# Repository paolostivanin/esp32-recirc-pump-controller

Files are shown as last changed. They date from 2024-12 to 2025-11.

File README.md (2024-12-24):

# ESP32 pump controller for Grundfos Comfort AutoAdapt recirculating hot water pump

This project contains a KiCad project for a replacement controller board that I
built for a Grundfos Comfort AutoAdapt recirculating hot water pump using an
ESP32-C3-MINI-1 board. This allows the pump to be controlled remotely, and
integrated in to Home Assistant using [ESPHome][esphome].  There's some more information 
on this in the [Home Assistant community forum](https://community.home-assistant.io/t/hacking-a-grundfos-comfort-autoadapt-recirculating-hot-water-pump-for-esphome/684475).

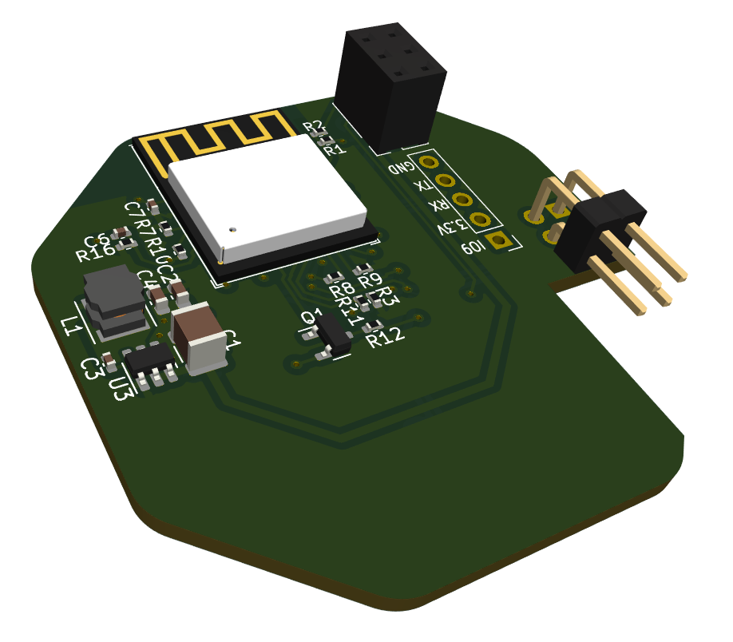
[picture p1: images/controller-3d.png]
PCB 3D render


The AutoAdapt pump is supposed to predict when you need hot water based on
previous usage patterns, but it never worked reliably for me. I originally
planned to put the pump into "always on" mode and use an external relay to
control it from Home Assistant, but unfortunately, every time you cut the power
to the pump, it reverts to AutoAdapt mode. I originally started
reverse-engineering the pump to figure out if it was possible to force it to be
always on (you can quite easily) but then got a bit carried away with a better
solution.

_Obvious warnings: copy this at your own risk. The board was designed based on
reverse engineering of the original board, so it's quite possible that I missed
some important safety considerations when doing so. The pump is mains powered,
so disconnect it before disassembly, and be aware that capacitors on the the
power supply board may still hold charge. If you don't understand what this
means, stop now._

## Original control board

The pump contains 3 PCBs. The front board is the control board. The middle
board is the power supply, and the rear board is the motor driver.

The modular design of the PCBs makes it quite easy to swap in a different
control board that re-uses the existing power supply and motor driver boards.

The power supply board provides 14V to the other two boards. The motor board
provides a 5V supply which is used by the microcontrollers on both the motor 
board and the control board.

The control board connects to the power supply board via a six pin connector
with the following pins (facing the control board connector):

```
+---------+---------+---------+
|  Temp   |   5V    |    0V   |
+---------+---------+---------+
|  Motor  |   ??    |   14V   |
+---------+---------+---------+
```

The original controller uses a PIC18F14K50 microcontroller.

The motor control appears to be an active-high, open-drain arrangement, meaning that the
controller pulls it to ground to turn the motor off, and lets it float (pulled up by PSU board) to 
turn it on. This means that if you simply remove the control board, the pump will
run all the time. The circuit on the motor controller looks like this may actually be treated 
as an analog input, possibly allowing control of motor speed.

I'm unsure of the details of the pump temperature sensor, beyond that it gives an
analog signal that varies with the temperature of the pump.  The replacement
board feeds it into a potential divider to ensure that it remains < 3.3V, and I
then calibrated it empirically. This is used to measure the temperature of
water flowing out of the tank.

The `??` pin is connected to the analog ground reference voltage input (AVss)
on the microcontroller (30F2010) on the motor driver board. It's connected to ground
on the controller board, but appears to be pulled up to 5V by the PSU board.  I
don't understand this arrangement. The replacement board just connects it to ground
as per the original.

The other input to the board is from an external temperature sensor used to
measure the temperature of returning water. This is a simple 10K NTC, and
connects via 2 pins on a 4 pin header.

### Pump variants

This pump is sold in a few different variants with different controllers. My
guess is that these are identical internally except for the front control board
and face plate. The advantage of the "AutoAdapt" variant is that it has the
external return temperature sensor.

## Disassembly

The front of the pump is held on by four clips, and can be removed by carefully
levering behind the face plate around the circumference of the pump.  

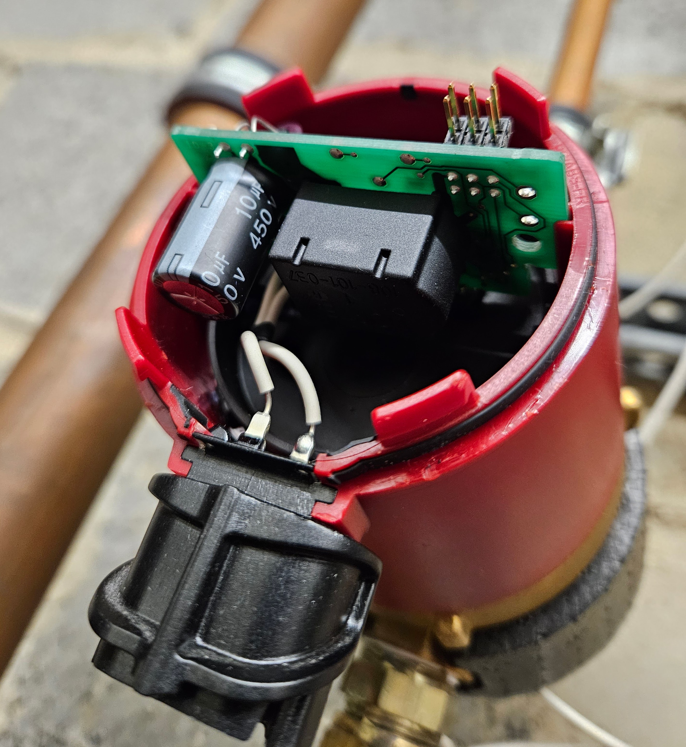
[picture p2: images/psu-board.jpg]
PSU board


The external temperature sensor is coiled around the face plate, and is also just
clipped on. Once removed, it can be unplugged from the board (I think there may
have been a spot of glue originally), and then the original PCB can be removed - it's 
held in by 4 clips which need to be gently bent back.

At this point, the power supply board can also be removed by pulling on it, but
you don't need to.

The motor driver PCB is hidden under a plastic cover that is _extremely_ hard
to remove, but you definitely don't need to.

## ESP32 control board

The replacement board uses an ESP32-C3-MINI-1 module. It has its own buck
regulator supply to drop the 14V input to 3.3V, as the 5V linear regulator
supply from the motor controller is almost certainly insufficient for the
ESP32.

The power supply uses an AP63203, and can be populated using the components
from a [SparkFun BabyBuck Regulator Breakout Board](https://thepihut.com/products/sparkfun-babybuck-regulator-breakout-3-3v-ap63203).

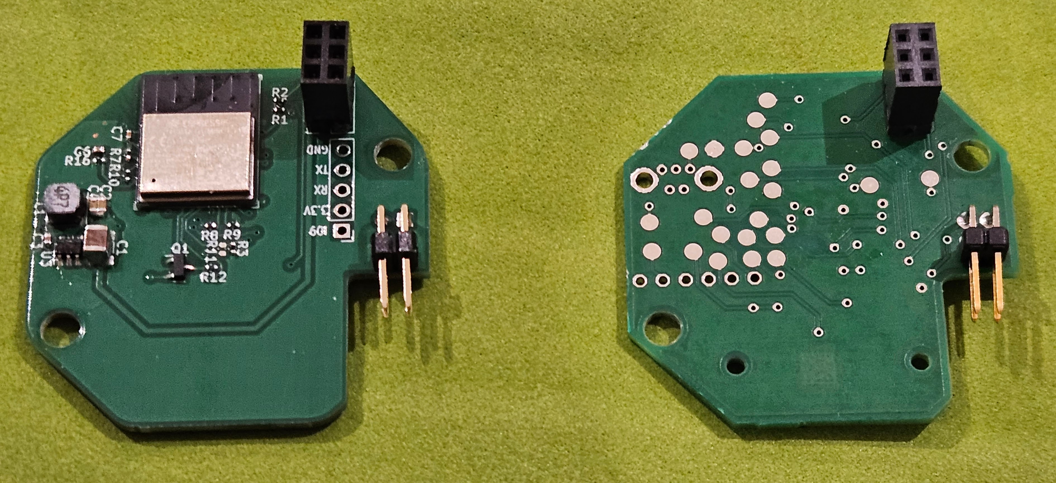
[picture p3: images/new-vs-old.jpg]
New vs old


The other parts of the board are:

### Motor driver

This uses an AO3400A MOSFET, and has a 680R series resistor because that's what
the original board had.

### Pump temperature input

This uses a potential divider to ensure that the input signal from the 5V
driver board remains less than 3.3V.

### Return temperature input

This uses a 10K resistor to form a potential divider.

### Switch input

The front panel switch pulls this to ground. The switch is a 2x3mm SMD tactile
switch.  I used a [CUI TS19-32-06-BK-70-1-SMT-TR-67](https://www.lcsc.com/datasheet/lcsc_datasheet_2312270104_CUI-TS19-32-06-BK-70-1-SMT-TR-67_C6723741.pdf).

### LED outputs

There are five LEDs on the front panel:

* Thermometer logo
* "Auto-adapt" logo (2 LEDs)
* "100%" logo
* "Sensor" logo

These are 0603 size LEDs.

I made the first four blue, and the last one red, and all have suitable
current-limiting resistors (0402).

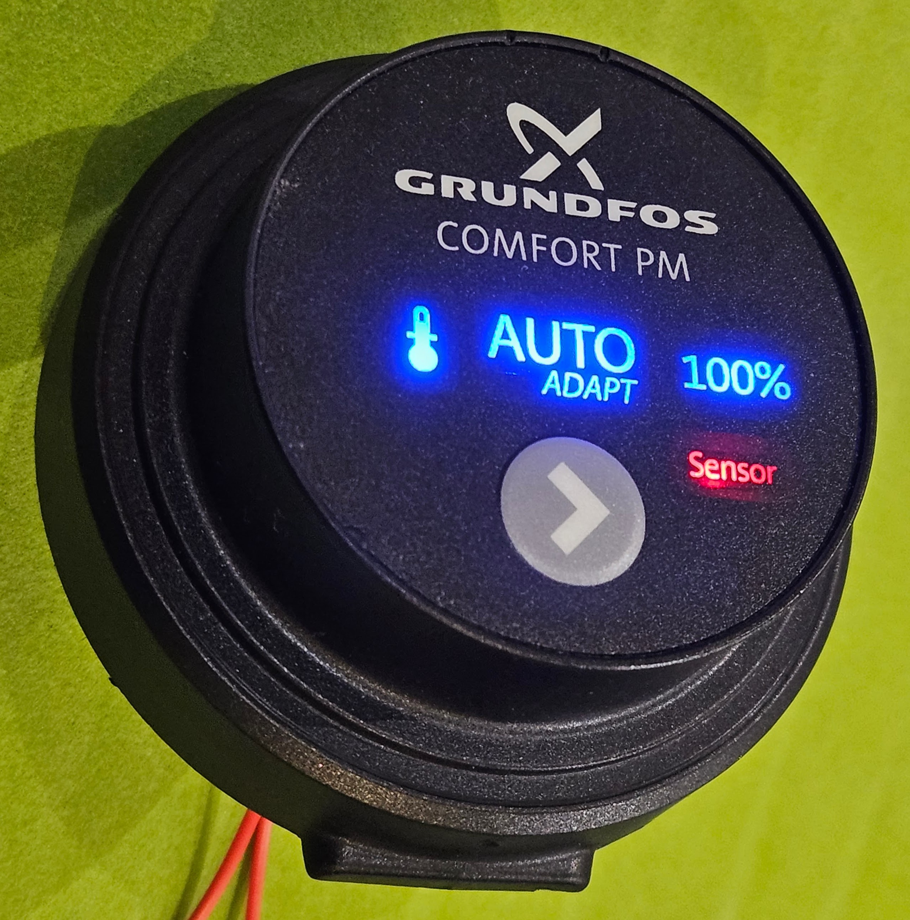
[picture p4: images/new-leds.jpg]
LEDs on new board


### Connectors

The six pin connector for the power supply is an almost-standard 2x3 2.54mm
female header, but it's taller than normal. Obviously you could steal the
connector from the old board, but I wanted to keep the old one intact. I
managed to find some headers with extra long pins, and added some spacers taken
from other header pins.

The temperature connector is a standard 2x2 right angle 2.54mm pin header.

The board has holes for exposing the ESP32 UART and power, but I've not used
these. There may not be enough clearance between the back of the board and the
front panel if you fit these.

## Board revisions

I made a mistake in the design and connected the pump temperature input to
GPIO5/ADC2 which is apparently incompatible with enabling wifi on the ESP32-C3.
I fixed this by swapping GPIO4 and GPIO5 with jumper wires, and have updated
the PCB design in this repo to match, but this does mean that the PCB in this
repository has technically never been built or tested.

## Board fabrication / assembly

I got my boards made by PCBWay, and assembled them myself. Most resistors and
diodes are 0402 because I have lots of these already, but there's space to make
them bigger.

If hand-soldering 0402 components is not your idea of fun, you could probably
get the front of the board assembled by PCBWay / JLCPCB, leaving just the LEDs,
resistors and switch to do on the back, and the connectors.  You could fairly
easily increase the size of the resistors to make soldering easier.

## ESPHome

My ESPHome configuration is available [here](esphome/pump-controller.yaml).

## Schematic

Schematic

[esphome]: https://esphome.io

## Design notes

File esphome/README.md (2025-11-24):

# HW Pump Controller – ESPHome (v4.0)

Smart ESPHome controller for **hot-water recirculation pumps** with ΔT logic, Boost mode, Legionella flush, runtime failsafes, and full LED status indication.  
Designed for **ESP32-C3 (DFRobot Beetle ESP32-C3)** and integrates automatically with Home Assistant via ESPHome API.

Thanks to @pdw-mb (https://github.com/pdw-mb) for the extensive work on this project and for providing the PCB. I only applied a few small adjustments to better fit my specific use case.

---

## Features

### Pump Control Logic
- ΔT = **Flow temperature − Return temperature**
- Pump turns **ON** when ΔT > ON threshold  
- Pump turns **OFF** when ΔT < OFF threshold  
- ON/OFF thresholds are adjustable from Home Assistant

### Operating Modes
- **Manual switch** from HA (`switch.pump`)
- **Boost mode**: 4 minutes  
- **Legionella flush**: 6 minutes  
- **Physical button**:
  - Short press → Boost  
  - Long press (≥3s) → Legionella  

### Safety & Protection
- Boost & Legionella are **mutually exclusive**
- If either temperature sensor is invalid for >60s → **pump forced OFF**
- If pump runs continuously for >10 minutes → **failsafe OFF**
- Timers **persist across reboots** and resume automatically

### Offline Operation
All logic (Boost, Legionella, ΔT control, failsafes) works **even if Wi-Fi or Home Assistant are offline**.

---

## Startup Behavior

1. LEDs enter sleep mode  
2. Pump state resets to OFF  
3. Any active timer is automatically resumed:
   - **Boost** → LED4 ON  
   - **Legionella** → LED5 ON  
4. Pump logic is recalculated immediately

If no timer is active → idle mode (LED2/LED3 sleeping).

---

## Home Assistant Entities (via ESPHome API)

| Entity ID | Type | Description |
|---|---|---|
| `switch.pump` | Switch | Main logical pump control |
| `button.boost_pump` | Button | Start Boost (4 min) |
| `button.legionella_flush` | Button | Start Legionella flush (6 min) |
| `binary_sensor.pump_state` | Binary Sensor | Physical relay state |
| `binary_sensor.pump_button` | Binary Sensor | Physical button |
| `sensor.boost_timer` | Sensor | Boost time remaining (minutes) |
| `sensor.legionella_timer` | Sensor | Legionella time remaining (minutes) |
| `sensor.flow_temperature` | Sensor | Flow/supply water temperature |
| `sensor.pump_temperature` | Sensor | Return temperature |
| `sensor.delta_temp` | Sensor | Flow − Pump ΔT |
| `number.pump_delta_t_on_threshold` | Number | Activation threshold |
| `number.pump_delta_t_off_threshold` | Number | Deactivation threshold |

Internal LEDs (`led2–led5`) are hidden from HA.

---

## LED Behavior

### **LED1 — Blue (Thermometer)**
- OFF → Pump OFF  
- Solid ON → Pump ON  
- Pulse → Pump just activated (ΔT trigger)

### **LED2 & LED3 — Green (Auto-Adapt)**
- Solid ON → Logic active  
- Slow pulse → Idle (waiting for ΔT or timer)

### **LED4 — Amber (Boost)**
- Fast pulse → Boost active  
- OFF → No boost

### **LED5 — Red (Legionella)**
- Solid ON → Legionella active  
- OFF → Not active

---

## Safety Mechanics

- **Sensor failure**  
  - If flow or return temperature becomes NaN for >60s → pump OFF  

- **Maximum runtime**  
  - Pump cannot run >10 minutes continuously unless ΔT keeps it cycling normally  
  - Failsafe OFF triggers if exceeded  

- **Timer exclusivity**  
  - Starting Boost automatically stops Legionella and vice-versa  

---

## Notes

- All timers shown in **minutes**.
- ΔT thresholds adjustable from HA.
- System works even without Home Assistant.
- ESP-IDF is required for ESP32-C3 Beetle

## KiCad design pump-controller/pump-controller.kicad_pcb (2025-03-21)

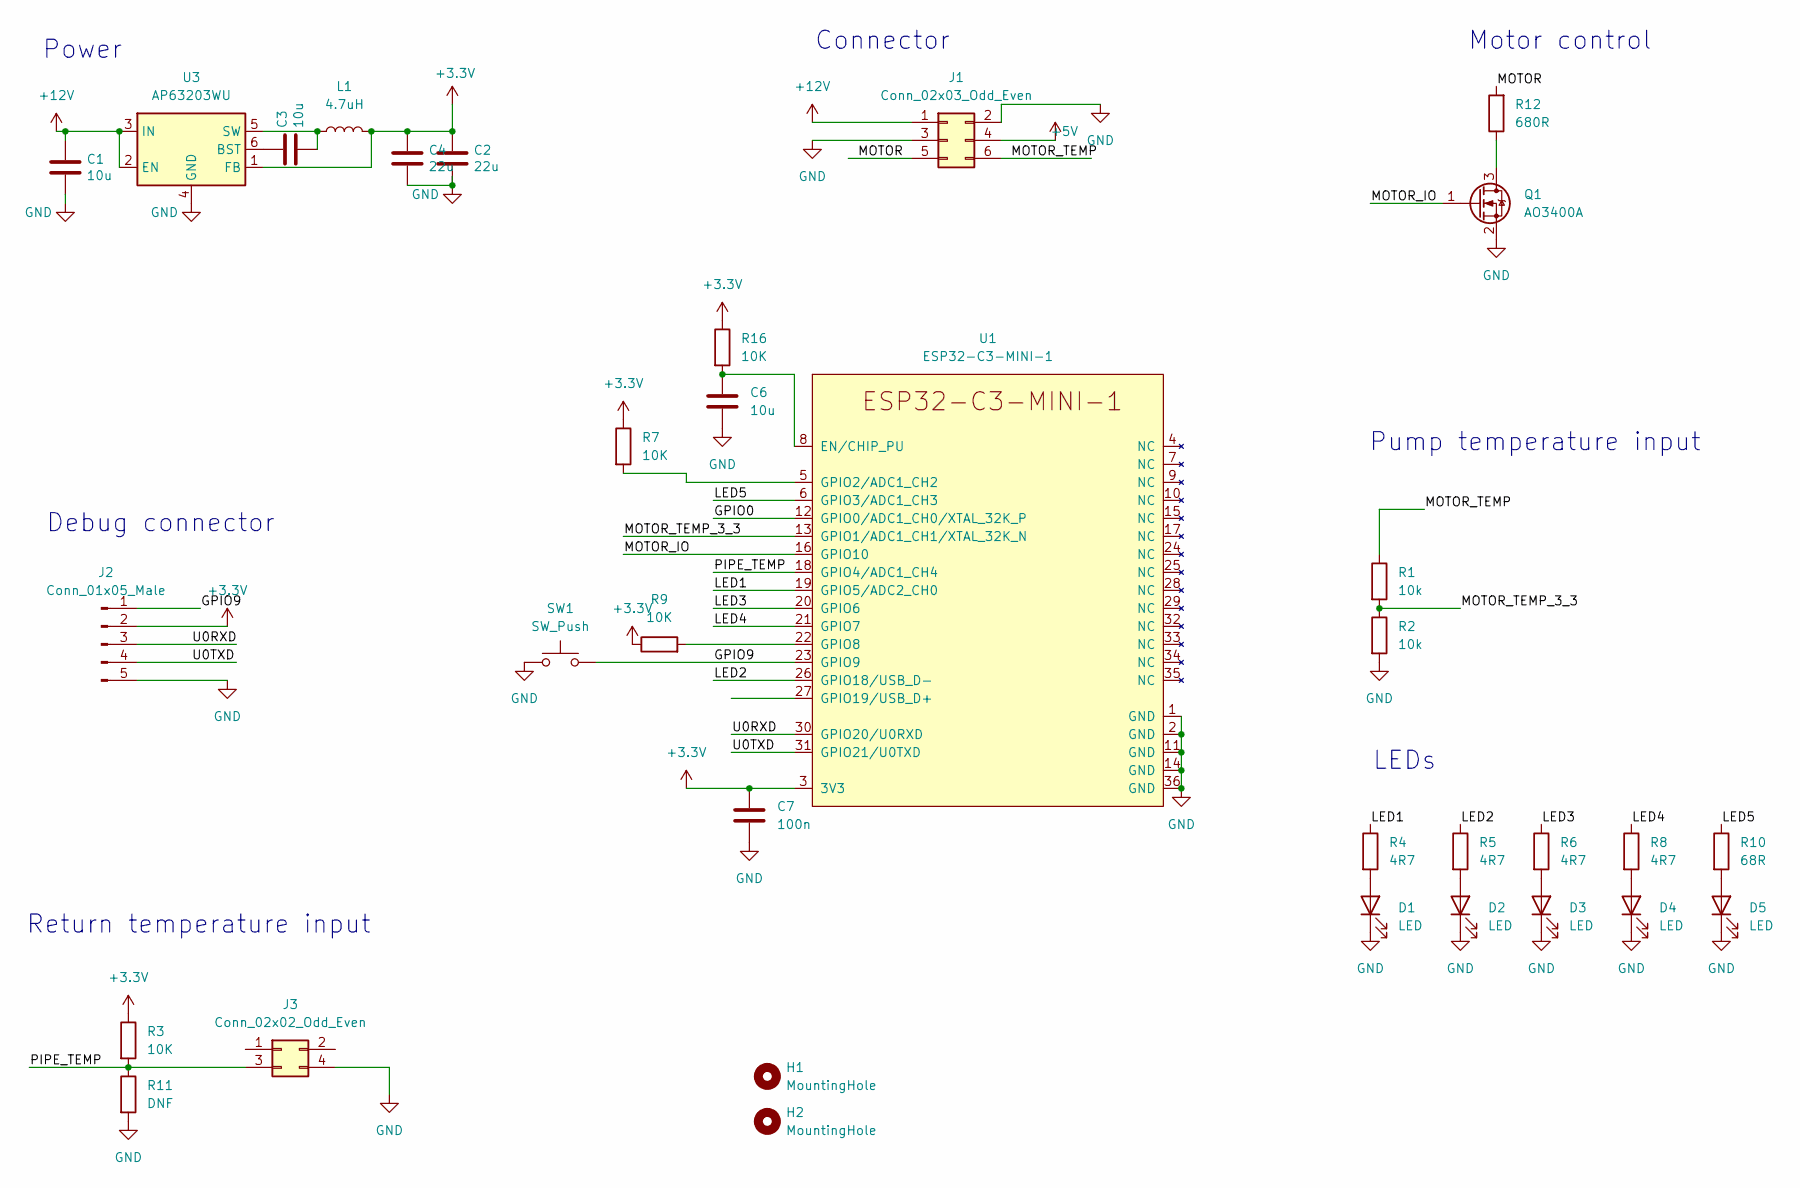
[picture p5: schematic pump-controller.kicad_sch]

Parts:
C1: 10u; C_1206_3216Metric
C2, C4: 22u; C_0805_2012Metric
C3, C6: 10u; C_0402_1005Metric
C7: 100n; C_0402_1005Metric
D1, D2, D3, D4, D5: LED; LED_0603_1608Metric
H1, H2: MountingHole; MountingHole_4mm
J1: Conn_02x03_Odd_Even; PinSocket_2x03_P2.54mm_Vertical
J2: Conn_01x05_Male; PinHeader_1x05_P2.54mm_Vertical
J3: Conn_02x02_Odd_Even; PinHeader_2x02_P2.54mm_Horizontal
L1: 4.7uH; L_Abracon_ASPI-4030S
Q1: AO3400A; SOT-23
R1, R2: 10k; R_0402_1005Metric
R3, R7, R9, R16: 10K; R_0402_1005Metric
R4, R5, R6, R8: 4R7; R_0402_1005Metric
R10: 68R; R_0402_1005Metric
R11: DNF; R_0402_1005Metric
R12: 680R; R_0402_1005Metric
SW1: SW_Push; TS193206BK701SMTTR67
U1: ESP32-C3-MINI-1
U3: AP63203WU; TSOT-23-6

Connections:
+3.3V: C2.1, C4.1, C7.1, J2.2, L1.2, R3.1, R7.1, R9.1, R16.1, U1.3 (3V3), U3.1 (FB)
+5V: J1.4
+12V: C1.1, J1.1, U3.2 (EN), U3.3 (IN)
/GPIO0: U1.12 (GPIO0/ADC1_CH0/XTAL_32K_P)
/GPIO9: J2.1, SW1.2, U1.23 (GPIO9)
/LED1: R4.1, U1.19 (GPIO5/ADC2_CH0)
/LED2: R5.1, U1.26 (GPIO18/USB_D-)
/LED3: R6.1, U1.20 (GPIO6)
/LED4: R8.1, U1.21 (GPIO7)
/LED5: R10.1, U1.6 (GPIO3/ADC1_CH3)
/MOTOR: J1.5, R12.2
/MOTOR_IO: Q1.1 (G), U1.16 (GPIO10)
/MOTOR_TEMP: J1.6, R1.1
/MOTOR_TEMP_3_3: R1.2, R2.1, U1.13 (GPIO1/ADC1_CH1/XTAL_32K_N)
/PIPE_TEMP: J3.3, R3.2, R11.1, U1.18 (GPIO4/ADC1_CH4)
/U0RXD: J2.3, U1.30 (GPIO20/U0RXD)
/U0TXD: J2.4, U1.31 (GPIO21/U0TXD)
GND: C1.2, C2.2, C4.2, C6.2, C7.2, D1.1 (K), D2.1 (K), D3.1 (K), D4.1 (K), D5.1 (K), J1.2, J1.3, J2.5, J3.4, Q1.2 (S), R2.2, R11.2, SW1.1, U1.1 (GND), U1.2 (GND), U1.11 (GND), U1.14 (GND), U1.36 (GND), U3.4 (GND)
unnamed: D1.2 (A), R4.2
unnamed: D2.2 (A), R5.2
unnamed: D3.2 (A), R6.2
unnamed: D4.2 (A), R8.2
unnamed: D5.2 (A), R10.2
unnamed: Q1.3 (D), R12.1
unnamed: C6.1, R16.2, U1.8 (EN/CHIP_PU)
unnamed: R7.2, U1.5 (GPIO2/ADC1_CH2)
unnamed: R9.2, U1.22 (GPIO8)
unnamed: C3.1, U3.6 (BST)
unnamed: C3.2, L1.1, U3.5 (SW)

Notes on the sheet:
LEDs
Power
Pump temperature input
Debug connector
Return temperature input
Motor control
Connector

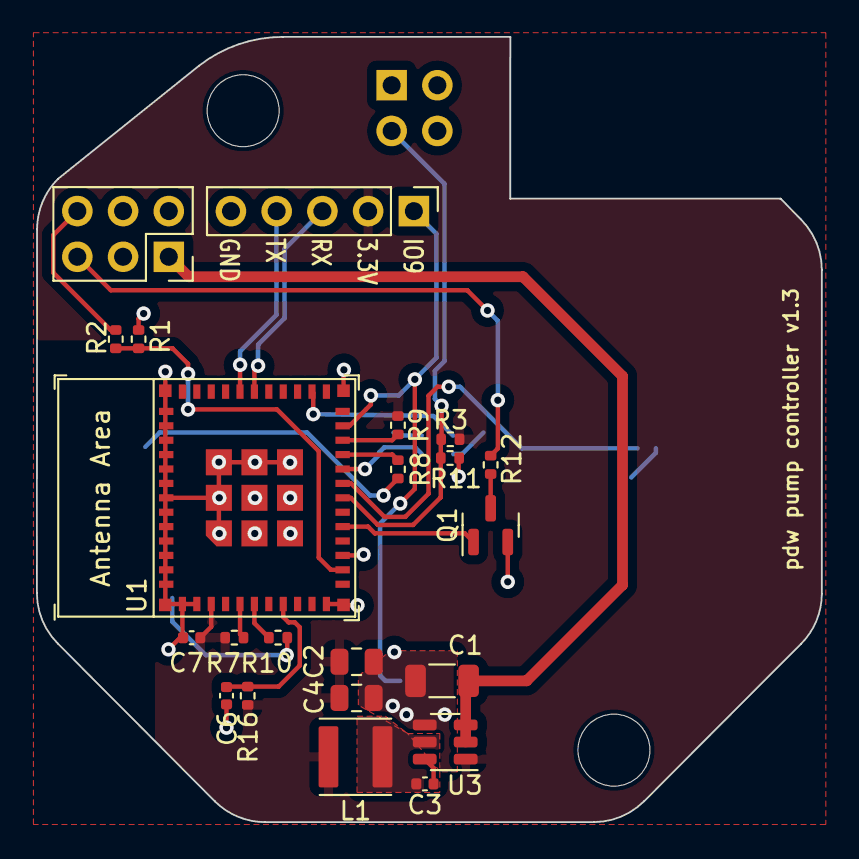
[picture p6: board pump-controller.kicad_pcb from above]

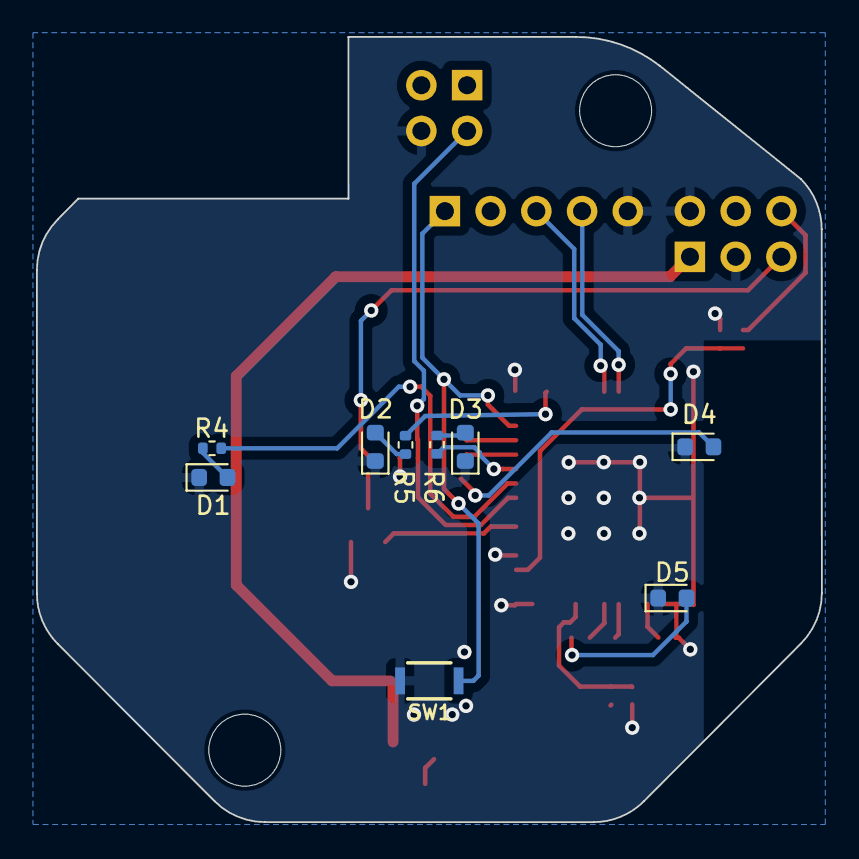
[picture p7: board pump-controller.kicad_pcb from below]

Board: 2 copper layers, 43.6 x 43.6 mm, 34 parts (9 on the bottom side), 27 nets.

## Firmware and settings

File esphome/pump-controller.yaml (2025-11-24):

esphome:
  name: hw-pump-controller
  friendly_name: HW Pump Controller
  on_boot:
    priority: 600
    then:
      # Initialize LEDs and state
      - script.execute: led_sleep_all
      - binary_sensor.template.publish:
          id: pump_state
          state: "OFF"
      - script.execute: update  # refresh LEDs + logic after boot

      # Resume timers if they were active before reboot
      - if:
          condition:
            lambda: 'return id(_boost_timer_remaining) > 0;'
          then:
            - logger.log: "Resuming Boost timer after reboot"
            - script.execute:
                id: led_on
                led: !lambda "return &id(led4);"
            - script.execute: boost_timer_tick
      - if:
          condition:
            lambda: 'return id(_legionella_timer_remaining) > 0;'
          then:
            - logger.log: "Resuming Legionella timer after reboot"
            - script.execute:
                id: led_on
                led: !lambda "return &id(led5);"
            - script.execute: legionella_timer_tick

esp32:
  board: dfrobot_beetle_esp32c3
  variant: ESP32C3
  framework:
    type: esp-idf

logger:
  level: INFO
  logs:
    custom: DEBUG
    main: DEBUG

# ---- Home Assistant API + OTA -----------------------------------------------
api:
  encryption:
    key: !secret esphome_hw_pump_api_key

ota:
  password: !secret esphome_hw_pump_ota_password

# ---- Wi-Fi + fallback AP ----------------------------------------------------
wifi:
  ssid: "IoT"
  password: !secret wifi_iot_password

  # Fallback hotspot if Wi-Fi fails
  ap:
    ssid: "ESP-Pump-Controller"
    password: !secret esphome_hw_pump_ap_password
    ap_timeout: 60s

captive_portal:
web_server:

# ---- Runtime state (globals) ------------------------------------------------
globals:
  - id: _boost_timer_remaining
    type: int
    initial_value: "0"
    restore_value: yes

  - id: _legionella_timer_remaining
    type: int
    initial_value: "0"
    restore_value: yes

  - id: _run_pump
    type: bool
    initial_value: "false"

  - id: _sensor_fail_counter
    type: int
    initial_value: "0"

  - id: _pump_max_runtime_counter
    type: int
    initial_value: "0"

# ---- User-adjustable thresholds (seen in HA) --------------------------------
number:
  - platform: template
    name: "Pump ΔT ON threshold"
    id: delta_on
    min_value: 5
    max_value: 30
    step: 1
    initial_value: 15

  - platform: template
    name: "Pump ΔT OFF threshold"
    id: delta_off
    min_value: 0
    max_value: 25
    step: 1
    initial_value: 10

# ---- Scripts (LED helpers, timers, control logic) ---------------------------
script:
  # LED helpers
  - id: led_on
    parameters: [led]
    then:
      - lambda: |-
          led->turn_on()
            .set_brightness(1.0f)
            .set_effect("None")
            .perform();

  - id: led_off
    parameters: [led]
    then:
      - lambda: |-
          led->turn_off().perform();

  - id: led_sleep
    parameters: [led]
    then:
      - lambda: |-
          led->turn_on()
            .set_effect("sleep")
            .perform();

  - id: led_pulse
    parameters: [led]
    then:
      - lambda: |-
          led->turn_on()
            .set_brightness(1.0f)
            .set_effect("pulse")
            .perform();

  - id: led_sleep_all
    then:
      - script.execute:
          id: led_sleep
          led: !lambda "return &id(led2);"
      - script.execute:
          id: led_sleep
          led: !lambda "return &id(led3);"

  # Boost timer - exclusive with Legionella
  - id: start_boost_timer
    then:
      - script.execute: boost_timer_off
      - script.execute: legionella_timer_off      # exclusivity
      - lambda: |-
          id(_boost_timer_remaining) = 240;  // 4 min * 60s
      - script.execute:
          id: led_on
          led: !lambda "return &id(led4);"
      - script.execute: update
      - script.execute: boost_timer_tick
      - logger.log: "Boost timer started"

  - id: boost_timer_tick
    mode: restart
    then:
      - delay: 1s
      - lambda: |-
          if (--id(_boost_timer_remaining) <= 0) {
            id(boost_timer_off).execute();
          } else {
            id(boost_timer_tick).execute();
          }

  - id: boost_timer_off
    then:
      - lambda: |-
          id(_boost_timer_remaining) = 0;
      - script.execute:
          id: led_off
          led: !lambda "return &id(led4);"
      - script.execute: update

  # Legionella timer - exclusive with Boost
  - id: start_legionella_timer
    then:
      - script.execute: legionella_timer_off
      - script.execute: boost_timer_off           # exclusivity
      - lambda: |-
          id(_legionella_timer_remaining) = 360;  // 6 min * 60s
      - script.execute:
          id: led_on
          led: !lambda "return &id(led5);"
      - script.execute: update
      - script.execute: legionella_timer_tick
      - logger.log: "Legionella timer started"
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

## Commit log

2024-12-24 KiCad project
    [pump-controller.kicad_pcb, pump-controller.kicad_sch]
2024-12-24 Add ESPHome config.
    [pump-controller.yaml]
2024-12-24 Move esphome config.
    [pump-controller.yaml]
2025-03-05 Trivial tweaks, added version number.
    [pump-controller.kicad_pcb]
2025-03-21 KiCad save.
    [pump-controller.kicad_sch]
2025-03-21 Add missing mounting holes, tweak capacitor footprints.
    [pump-controller.kicad_pcb, pump-controller.kicad_sch]
2025-09-26 pump-controller: add legionella timer and improve control logic
    Changes:
    - Added 5-minute legionella_timer script to force pump circulation
    after boiler anti-legionella cycle, ensuring 65 °C water flushes
    through all pipes.
    - Integrated legionella timer into pump control logic (update).
    - Exposed legionella_timer_remaining sensor for HA monitoring.
    - Fixed LED1 behavior (no longer lights when pump is OFF).
    - Rounded boost_timer_remaining to full minutes for cleaner display.
    - Added NaN checks for temperature sensors to avoid invalid control.
    - Marked diagnostic LEDs and raw ADC sensors as internal to reduce HA clutter.
    These changes improve safety and usability:
    - The dedicated legione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
    [pump-controller.yaml]
2025-09-26 pump-controller: refine thermometer LED behavior
    - LED1 (thermometer logo) now reflects pump status more clearly:
    * OFF when pump is OFF.
    * Flashing when pump just turned ON due to ΔT > 15 °C.
    * Solid ON when pump is running for other reasons (manual, boost, legionella, or stable ΔT).
    - Removed confusing case where LED1 could remain ON even if the pump was OFF.
    Why:
    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
    [pump-controller.yaml]
2025-09-26 pump-controller: extend physical button to trigger boost or legionella cycles
    - Updated GPIO button handler:
    * Short press (<1s) → start 30-minute Boost cycle.
    * Long press (≥3s) → start 5-minute Legionella flush.
    - Keeps existing HA entity ("Button") for diagnostics.
    This makes the front-panel button more versatile:
    - Quick short press ensures hot water availability before use.
    - Long press runs a hygienic flush after boiler anti-legionella cycle,
    without needing Home Assistant interaction.
    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
    [pump-controller.yaml]
2025-10-01 esp32: refactor pump controller
    - add MQTT auth + availability (online/offline) with HA discovery
    - add HA-configurable ΔT thresholds (number.delta_on / number.delta_off)
    - expose Legionella flush as HA button
    - enforce Boost/Legionella exclusivity
    - change LED1 from flash -> pulse for smoother UX
    - unify timer units to minutes
    - add LED helper scripts + tidy control flow
    - implement sensor-failure failsafe (>60s -> pump OFF)
    - add template binary_sensor "Pump State"
    - update README to v2
    [pump-controller.yaml]
2025-10-01 docs: update README to v3 with clearer entities and MQTT topics
    - Rewrite README to version 3:
    * Clarify ΔT definition (Flow − Return)
    * Show exact HA entity IDs and friendly names
    * Add ΔT Flow-Pump sensor in entity table
    * Separate MQTT topics into published vs subscribed
    * Improve LED behavior section wording
    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
    [pump-controller.yaml]
2025-10-20 Update to v3.3
    - Added symmetric ΔT updates (both flow/return sensors)
    - Added MQTT events topic section
    - Added logger DEBUG configuration example
    - Minor wording and LED pulse clarification
    [pump-controller.yaml]
2025-10-20 pump-controller: resume timers and restore switch state on reboot
    - Added robust on_boot resume logic:
    • Detects active Boost or Legionella timers after reboot.
    • Restarts countdown tickers and restores corresponding LEDs.
    • Publishes MQTT "resumed" events for HA visibility.
    • Forces update_pump_state to keep pump logic in sync.
    - Added `restore_mode: RESTORE_DEFAULT_OFF` to:
    • `_pump_control` GPIO relay (ensures safe startup)
    • `pump_control` template switch (consistent post-reboot state)
    Result:
    → Timers now survive reboots and continue counting down autonomously.
    → Pump relay and LEDs always start in a safe, known state.
    → HA receives consistent MQTT events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
    [pump-controller.yaml]
2025-11-24 v4.0 use HA api and not mqtt
    [pump-controller.yaml]
